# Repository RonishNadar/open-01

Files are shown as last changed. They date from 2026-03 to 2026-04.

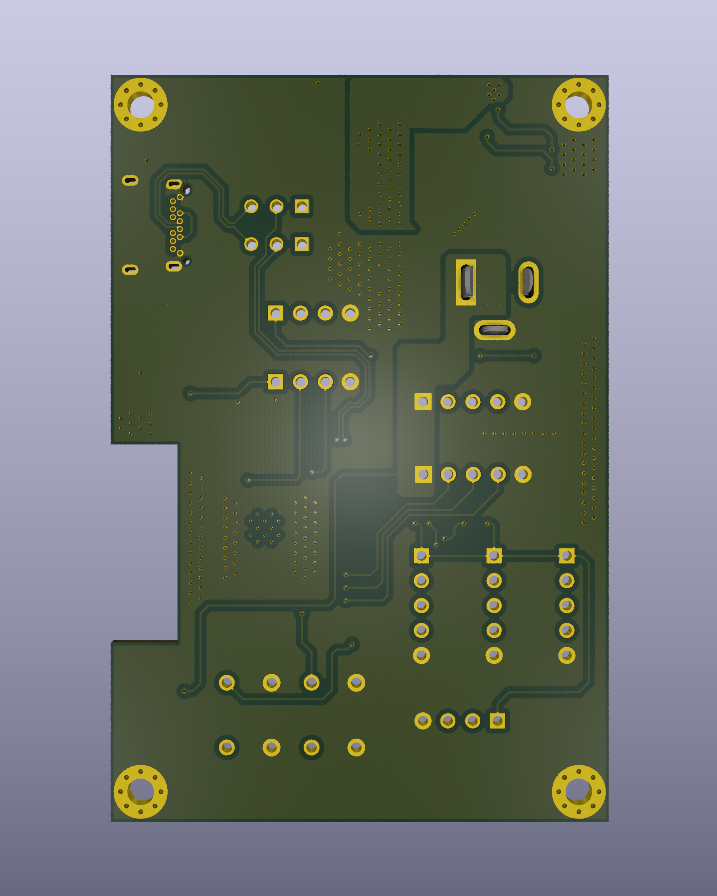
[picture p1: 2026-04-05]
pcb/images/open-01-pcb_v1.0.0_back.png

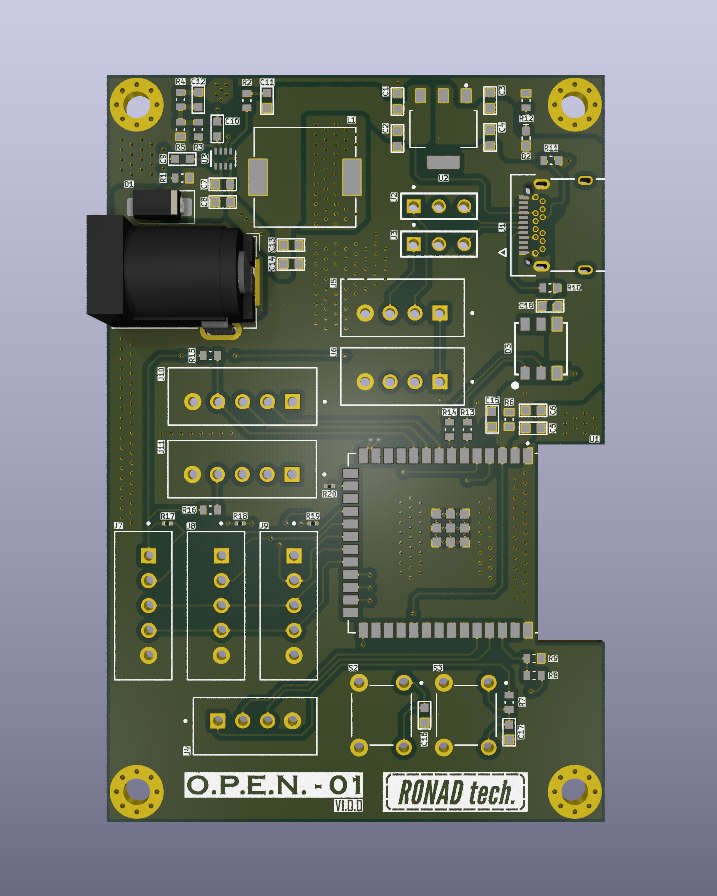
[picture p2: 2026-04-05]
pcb/images/open-01-pcb_v1.0.0_front.png

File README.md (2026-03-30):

# OPEN-01

**OPEN-01** is an open-source, low-cost differential drive robot platform focused on embedded sensing, motion control, and autonomous navigation.

This repository contains the full stack:
- ESP-IDF firmware for the ESP32-S2 robot controller
- ROS2 serial bridge and bringup for Raspberry Pi 3B
- URDF robot description with STL meshes
- RViz2 visualization stack for the dev laptop
- robot_localization EKF for sensor fusion
- Linux setup scripts for both machines

---

## What this repo is

OPEN-01 is designed as a low-cost, replicable alternative to the TurtleBot3. It is built around proven hardware and a clean layered architecture — embedded-first, with ROS2 as the autonomy layer on top.

The platform is structured around two compute nodes:

- **ESP32-S2** — handles all real-time firmware: sensors, motors, odometry, and UART telemetry
- **Raspberry Pi 3B** — runs ROS2 Humble, bridges ESP32 telemetry to ROS2 topics, and relays lidar data
- **Laptop** — runs EKF, SLAM, Nav2, and RViz2 visualization over WiFi

---

## Current capabilities

### Firmware (ESP32-S2)
- **Motor control** — FIT0441 brushless DC motors, 25kHz PWM, encoder feedback, startup kick
- **IMU** — MPU6500 (WHO_AM_I=0x70), dedicated I2C bus, accel + gyro
- **ToF ranging** — 3x VL53L0X (left, right, back), XSHUT-based address assignment
- **Odometry** — wheel encoder integration, kinematics
- **Battery monitoring** — 3S Li-Ion voltage via ADC with voltage divider
- **UART telemetry** — custom binary protocol at 460800 baud with CRC16-CCITT

### ROS2 Stack (Raspberry Pi 3B — ROS2 Humble)
- **Serial bridge node** — parses ESP32 binary protocol, publishes all sensor topics
- **Lidar node** — LDS-02 lidar via USB2LDS adapter, publishes `/scan` *(in progress)*
- **robot_state_publisher** — broadcasts full TF tree from URDF
- **Systemd autostart** — `open01.service` brings up the full stack on boot

### ROS2 Stack (Laptop — ROS2 Jazzy)
- **RViz2 visualization** — CAD model, TF frames, odometry, lidar scan
- **robot_localization EKF** — fuses `/odom` + `/imu/data` → `/odometry/filtered` at 30Hz
- **SLAM Toolbox** — *(planned)*
- **Nav2** — *(planned)*

### Published ROS2 Topics
| Topic | Type | Source |
|---|---|---|
| `/odom` | `nav_msgs/Odometry` | Serial bridge |
| `/imu/data` | `sensor_msgs/Imu` | Serial bridge |
| `/battery_state` | `sensor_msgs/BatteryState` | Serial bridge |
| `/tof/left` | `sensor_msgs/Range` | Serial bridge |
| `/tof/right` | `sensor_msgs/Range` | Serial bridge |
| `/tof/back` | `sensor_msgs/Range` | Serial bridge |
| `/scan` | `sensor_msgs/LaserScan` | Lidar node |
| `/joint_states` | `sensor_msgs/JointState` | Serial bridge |
| `/odometry/filtered` | `nav_msgs/Odometry` | EKF node |
| `/cmd_vel` | `geometry_msgs/Twist` | Nav2 / teleop |

---

## Hardware

| Component | Part |
|---|---|
| Microcontroller | ESP32-S2 |
| Companion computer | Raspberry Pi 3B |
| Motors | FIT0441 brushless DC with encoders |
| IMU | MPU6500 |
| ToF sensors | 3x VL53L0X |
| Lidar | LDS-02 (via USB2LDS adapter, CP210x) |
| Battery | 3S Li-Ion (12.6V full, 9.0V cutoff) |

### Pin Map (ESP32-S2)

| Function | GPIO |
|---|---|
| I2C Bus 0 SDA (ToF) | GPIO14 |
| I2C Bus 0 SCL (ToF) | GPIO13 |
| I2C Bus 1 SDA (IMU) | GPIO5 |
| I2C Bus 1 SCL (IMU) | GPIO4 |
| XSHUT Left (0x30) | GPIO12 |
| XSHUT Back (0x31) | GPIO11 |
| XSHUT Right (0x32) | GPIO10 |
| UART TX | GPIO19 |
| UART RX | GPIO20 |
| Motor Right PWM | GPIO15 |
| Motor Right DIR | GPIO16 |
| Motor Right FG | GPIO17 |
| Motor Left PWM | GPIO21 |
| Motor Left DIR | GPIO33 |
| Motor Left FG | GPIO34 |
| Battery ADC | GPIO2 |

---

## Repository structure

```text
open-01/
├── robot_firmware/              # ESP32-S2 firmware (ESP-IDF v5.4)
│   └── main/
│       ├── config/              # GPIO, timing, robot geometry constants
│       ├── common/              # Shared robot state
│       ├── drivers/             # MPU6500, VL53L0X, motor drivers
│       ├── hal/                 # Hardware abstraction layer
│       ├── services/            # PID, kinematics, odometry, comms
│       └── tasks/               # FreeRTOS tasks (IMU, ToF, motor, comms)
├── robot_ros2/
│   └── ros2_ws/
│       └── src/
│           ├── open01_serial_bridge/   # ESP32 <-> ROS2 bridge + lidar node
│           ├── open01_bringup/         # RPi launch files
│           ├── open01_description/     # URDF + STL meshes
│           └── open01_viz/             # Laptop RViz2 launch + EKF config
├── cad/
│   └── URDFs/                   # SolidWorks URDF export (source)
├── scripts/
│   ├── setup_rpi.sh             # One-command RPi setup
│   └── setup_laptop.sh          # One-command laptop setup
├── tools/
│   ├── launcher.py              # ESP-IDF GUI launcher
│   └── setup.sh                 # ESP-IDF toolchain setup
├── LICENSE
└── README.md
```

---

## Getting started

### RPi setup (Ubuntu 22.04 + ROS2 Humble)

```bash
git clone https://github.com/RonishNadar/open-01.git
cd open-01
sudo bash scripts/setup_rpi.sh
sudo reboot
```

### Laptop setup (Ubuntu 24.04 + ROS2 Jazzy)

```bash
git clone https://github.com/RonishNadar/open-01.git
cd open-01
sudo bash scripts/setup_laptop.sh
source ~/.bashrc
```

### Firmware setup (ESP32-S2)

```bash
chmod +x tools/setup.sh
./tools/setup.sh
python3 tools/launcher.py
```

---

## Running the robot

### On RPi (auto-starts on boot via systemd)
```bash
sudo systemctl start open01.service
sudo systemctl status open01.service
```

### Manual launch on RPi
```bash
cd ~/open-01/robot_ros2/ros2_ws
source install/setup.bash
ros2 launch open01_bringup bringup.launch.py
```

### Visualization + EKF on laptop
```bash
cd ~/open-01/robot_ros2/ros2_ws
source install/setup.bash
ros2 launch open01_viz viz.launch.py
```

### Verify topics
```bash
ros2 topic list
ros2 topic hz /odometry/filtered   # should be ~30Hz
ros2 topic hz /odom                # should be ~40Hz
ros2 topic hz /scan                # should be ~5Hz
```

### Verify TF tree
```bash
ros2 run tf2_tools view_frames
```

---

## Architecture

```
ESP32-S2 (firmware)
    |  UART 460800 baud (custom binary protocol, CRC16-CCITT)
    v
Raspberry Pi 3B (ROS2 Humble)
    |-- open01_serial_bridge  ->  /odom /imu/data /battery_state /tof/* /joint_states
    |-- lidar_node            ->  /scan
    |-- robot_state_publisher ->  /tf /tf_static
    |  WiFi (DDS, ROS_DOMAIN_ID=0)
    v
Laptop (ROS2 Jazzy)
    |-- robot_localization EKF  ->  /odometry/filtered
    |-- SLAM Toolbox            ->  /map (planned)
    |-- Nav2                    ->  autonomous navigation (planned)
    |-- RViz2                   ->  visualization
```

---

## Firmware architecture

### `config/`
Central constants: GPIO assignments, I2C/UART config, task periods, robot geometry, PID defaults.

### `common/`
Shared robot state and data structures accessed across tasks.

### `drivers/`
Low-level device drivers for MPU6500, VL53L0X, and motor control.

### `hal/`
Hardware abstraction layer separating board-specific logic from services.

### `services/`
Reusable robotics logic: PID, kinematics, odometry, motor coordination, UART comms.

### `tasks/`
FreeRTOS task entry points for periodic runtime behavior. All tasks pinned to Core 0 (ESP32-S2 is single-core).

---

## Key implementation notes

- **ESP32-S2 ADC** is 13-bit — `ADC_BITWIDTH_DEFAULT`, `BATTERY_ADC_MAX = 8191.0f`
- **FIT0441 motors** use inverted PWM (255=stop, 0=full speed), require 25kHz PWM and startup kick
- **FG pins** need 5kΩ external pull-up to 3.3V (open-collector output)
- **VL53L0X** requires full Pololu init sequence (SPAD calibration, 60+ tuning registers)
- **LDS-02 checksum** is `(~sum(bytes[0:40])) & 0xFF`, `INDEX_MAX=0xDB`
- **Serial port** on Ubuntu 22.04 RPi is `/dev/ttyS0` (not `/dev/ttyAMA0`)
- **ROS2 QoS** — RPi nodes publish `BEST_EFFORT`, set RViz2 subscriptions to match
- **EKF** — IMU orientation not fused (MPU6500 has no magnetometer), only `vyaw`, `ax`, `ay` used from IMU

---

## Project status

### Firmware
- [x] ESP-IDF firmware scaffold
- [x] Shared robot state
- [x] Motor control task + PID
- [x] IMU task (MPU6500)
- [x] ToF task (3x VL53L0X)
- [x] Odometry + kinematics
- [x] Battery monitoring
- [x] UART comms task (custom binary protocol)
- [x] Linux setup script + GUI launcher

### ROS2
- [x] Serial bridge node (ESP32 <-> ROS2)
- [~] LDS-02 lidar node *(in progress — lidar bring-up)*
- [x] URDF robot description
- [x] TF tree (all frames)
- [x] RViz2 visualization
- [x] Systemd autostart
- [x] Setup scripts (RPi + laptop)
- [x] robot_localization EKF (fusing /odom + /imu/data)
- [ ] SLAM Toolbox
- [ ] Nav2
- [ ] PID gain tuning

### Documentation
- [ ] Hardware wiring guide
- [ ] Full system bring-up docs
- [ ] Demo videos

---

## Contributing

Contributions are welcome. Good areas:

- hardware abstraction cleanup
- sensor validation and calibration
- motion control improvements
- Nav2 / SLAM configuration
- documentation and wiring diagrams
- testing utilities

When contributing:
1. keep modules focused
2. avoid hardcoding constants outside `config.h`
3. preserve the layered firmware structure
4. document any hardware assumptions clearly

---

## License

Licensed under the **Apache-2.0 License**. See [`LICENSE`](LICENSE) for details.

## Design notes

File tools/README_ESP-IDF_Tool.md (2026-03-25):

# Robot Firmware Tools

## First Time Setup (run once after cloning)

```bash
chmod +x tools/setup.sh
./tools/setup.sh
```

This will:
- Install all system dependencies (apt/dnf/pacman auto-detected)
- Clone and install ESP-IDF v5.4
- Add `idf` alias to your shell
- Add your user to the `dialout` group for USB access
- Install Python GUI dependencies

## GUI Launcher

```bash
python3 tools/launcher.py
```

| Button | What it does |
|---|---|
| Build | Compile the firmware |
| Flash | Write to ESP32-S2 |
| Monitor | Open serial monitor (Ctrl+C to stop) |
| Build+Flash+Monitor | All three in sequence |
| Clean | Full clean build |
| Stop | Kill the running command |

## CLI (alternative)

```bash
# Activate ESP-IDF in any terminal
idf

# Then use idf.py directly
cd firmware
idf.py build
idf.py -p /dev/ttyACM0 flash monitor
```

## Requirements

- Linux (Ubuntu/Debian/Fedora/Arch)
- Python 3.8+
- python3-tk (installed by setup.sh)

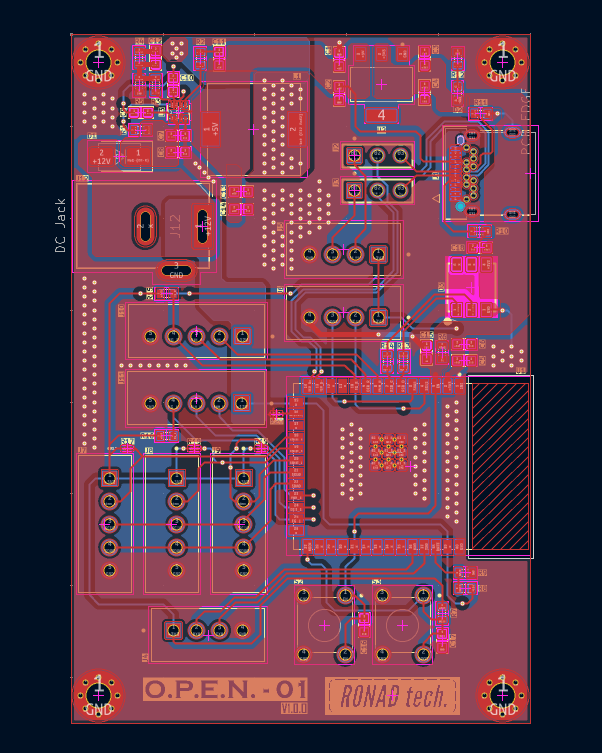
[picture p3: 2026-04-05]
pcb/images/open-01-pcb_v1.0.0_layout.png

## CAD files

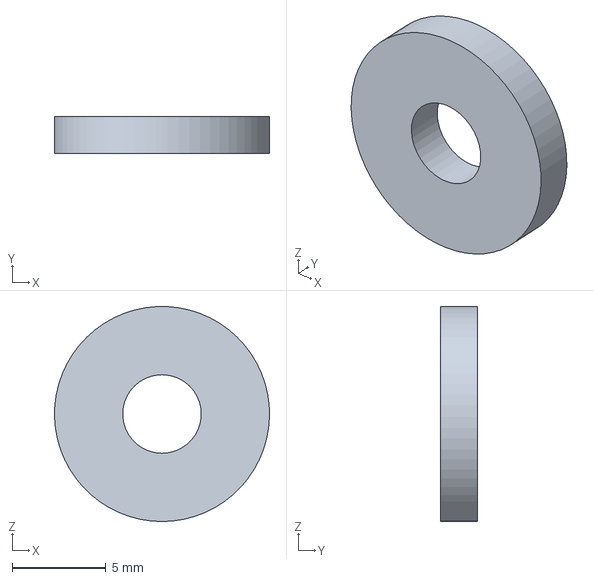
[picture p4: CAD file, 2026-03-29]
cad/3MFs/Wheel_Spacer_2mm.3MF
11.5 x 2.00 x 11.5 mm

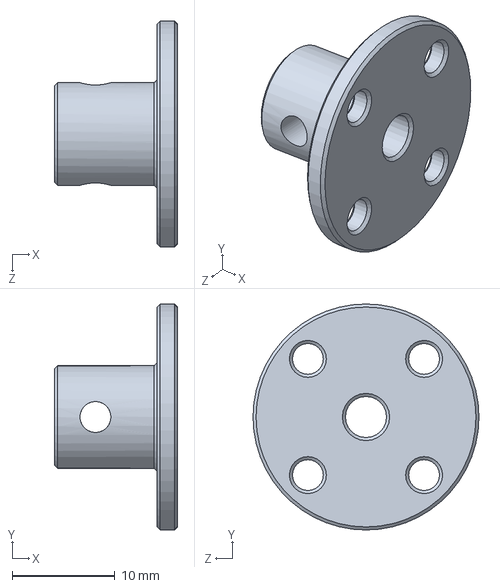
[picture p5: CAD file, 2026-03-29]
cad/Parts/Motor_Coupling_Hub_4mm.SLDPRT
12.0 x 22.0 x 22.0 mm

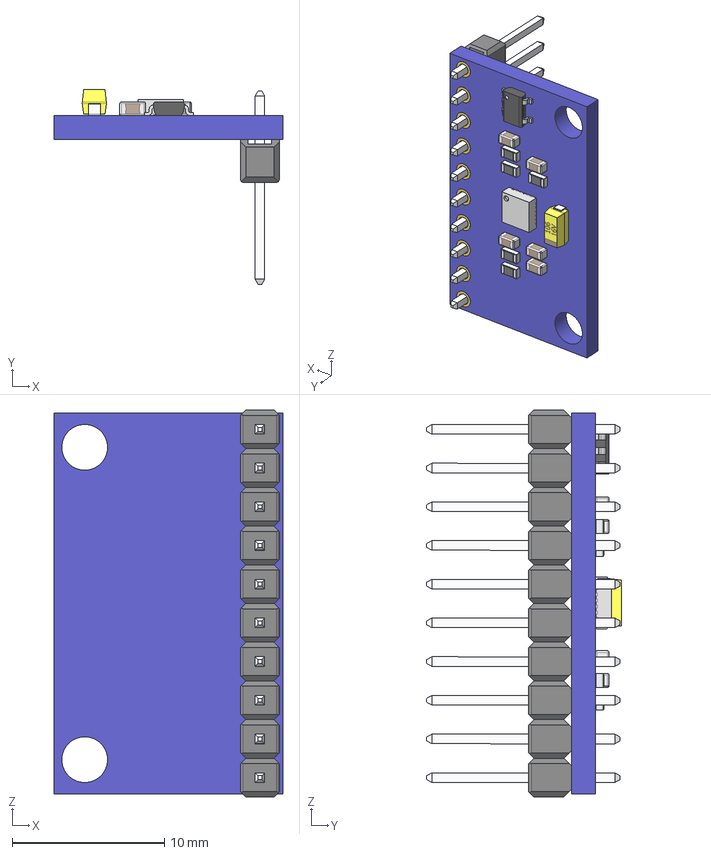
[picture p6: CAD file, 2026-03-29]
cad/STEPs/PCB_MPU_9250.stp
15.0 x 12.8 x 25.4 mm
board
hole_plating x 20
Pin Header 1x10 TH Pitch 2.54mm
MPU-9250_1
tantalum 10uF
SOT23_5
RESC-0603 x 5
CAPC-0603-T0.9-BN x 5

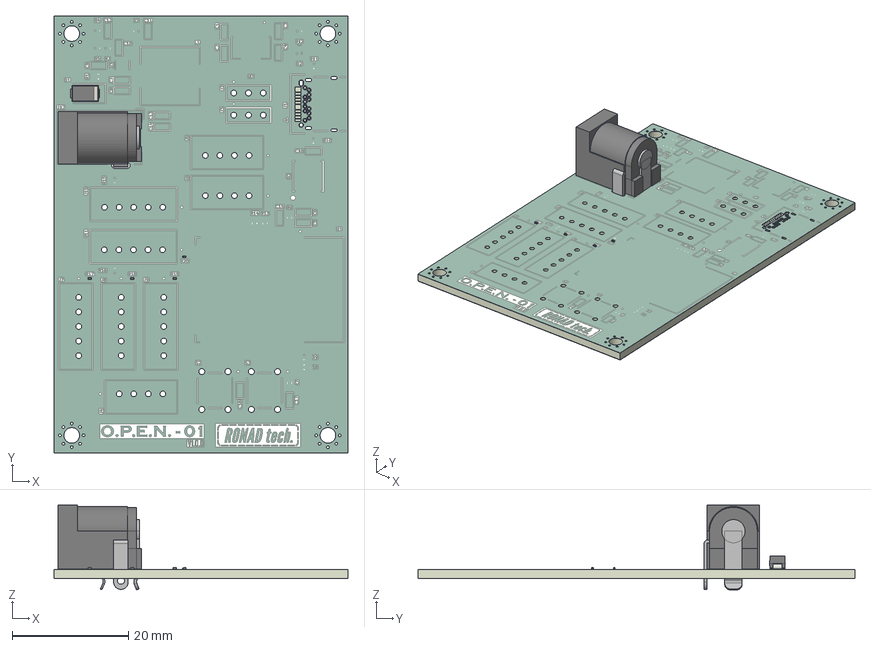
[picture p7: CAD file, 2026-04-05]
pcb/step-file/open-01-pcb_v1.0.0_step_file.step
50.5 x 75.1 x 14.6 mm
R_0201_0603Metric x 4
D_SMA
BarrelJack_GCT_DCJ200-10-A_Horizontal
open-01-pcb_silkscreen
open-01-pcb_soldermask x 2
open-01-pcb_PCB

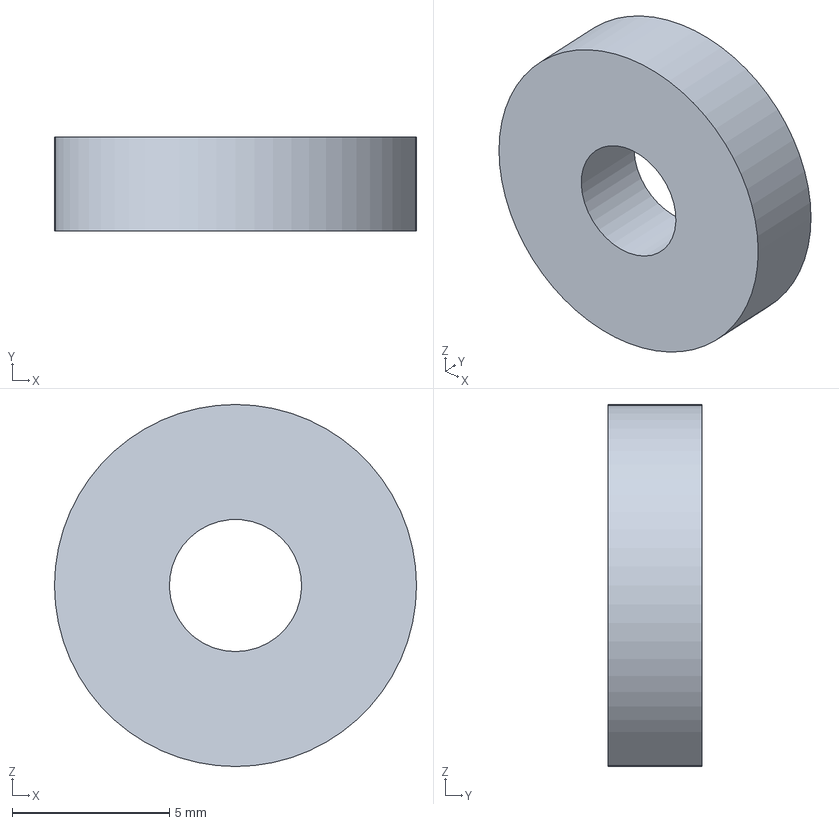
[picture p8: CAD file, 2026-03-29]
cad/3MFs/Wheel_Spacer_3mm.3MF
11.5 x 3.00 x 11.5 mm

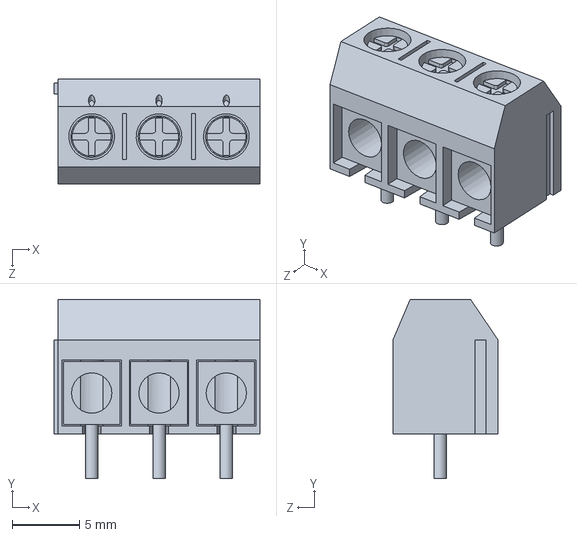
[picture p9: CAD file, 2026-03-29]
cad/Parts/PCB_Terminal_Block_3.SLDPRT
15.3 x 13.3 x 7.80 mm

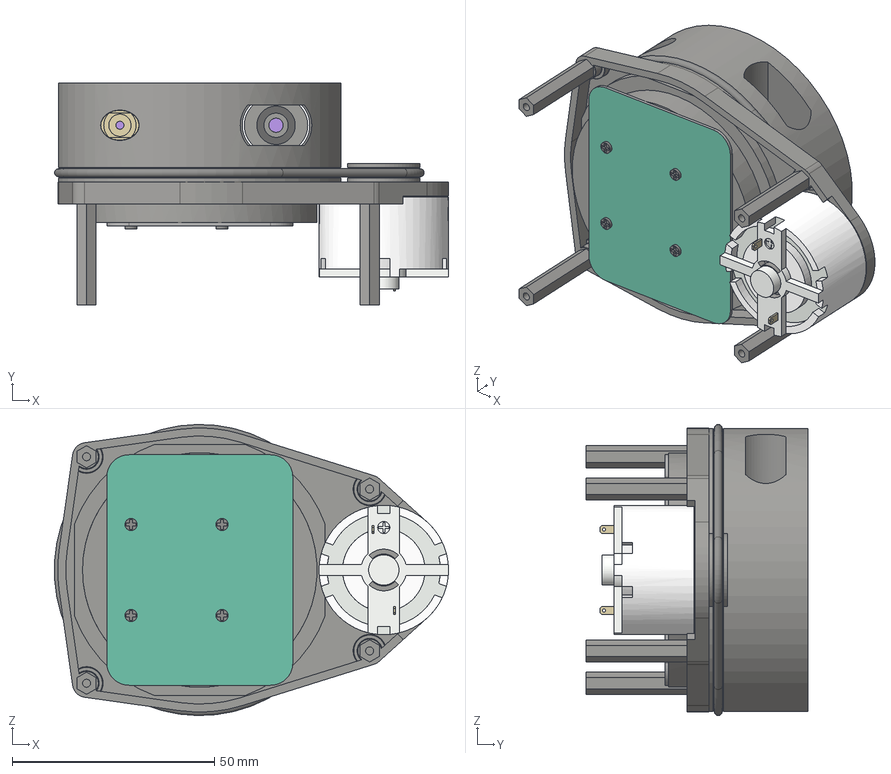
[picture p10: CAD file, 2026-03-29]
cad/STEPs/Lidar_A1M8.stp
97.4 x 55.0 x 72.0 mm

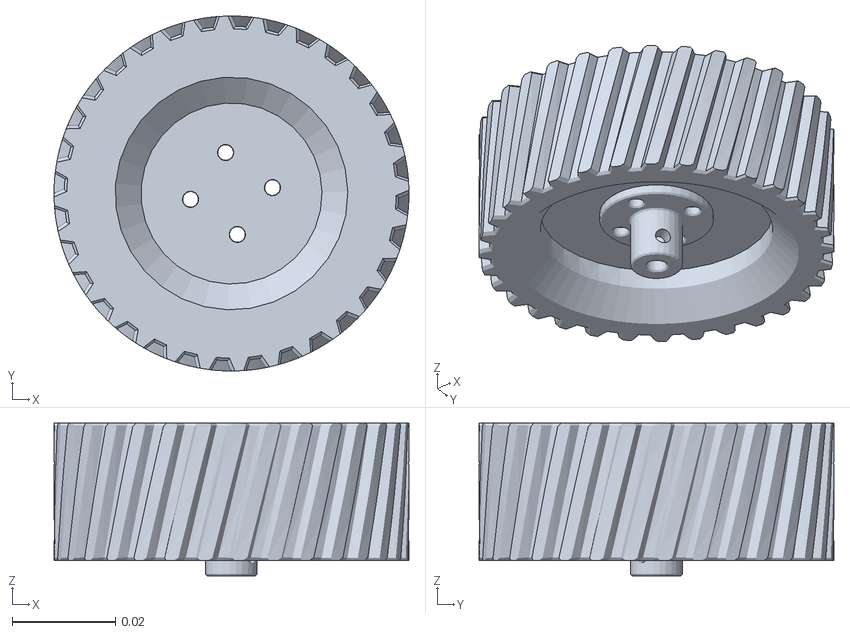
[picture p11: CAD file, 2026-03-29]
robot_ros2/ros2_ws/src/open01_description/meshes/Left_Wheel.stl
0.0686 x 0.0686 x 0.0295

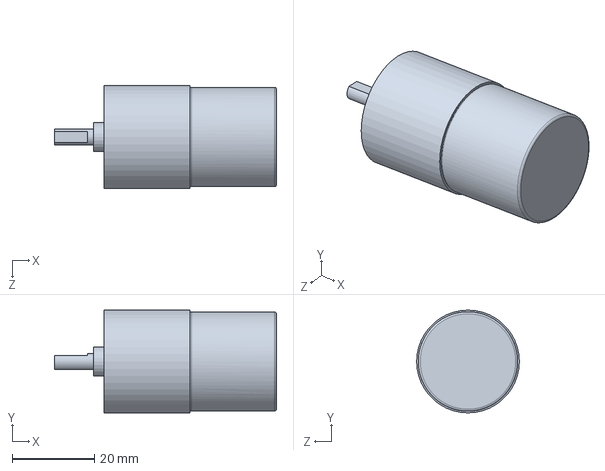
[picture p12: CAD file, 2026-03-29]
cad/Parts/DC_Motor_DF_Robot_FIT0441.SLDPRT
54.0 x 25.0 x 25.0 mm

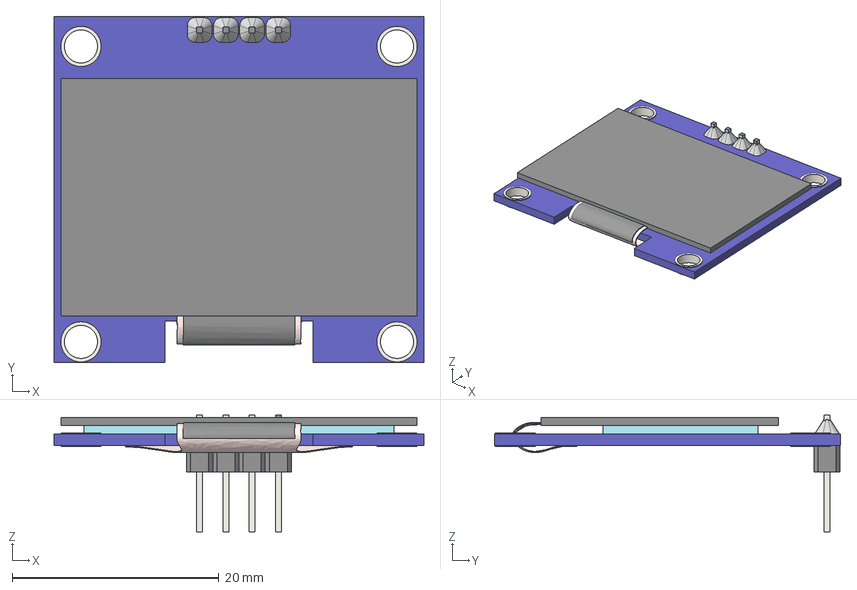
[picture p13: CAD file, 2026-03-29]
cad/STEPs/Display_OLED_1.3in.step
35.8 x 33.5 x 11.3 mm

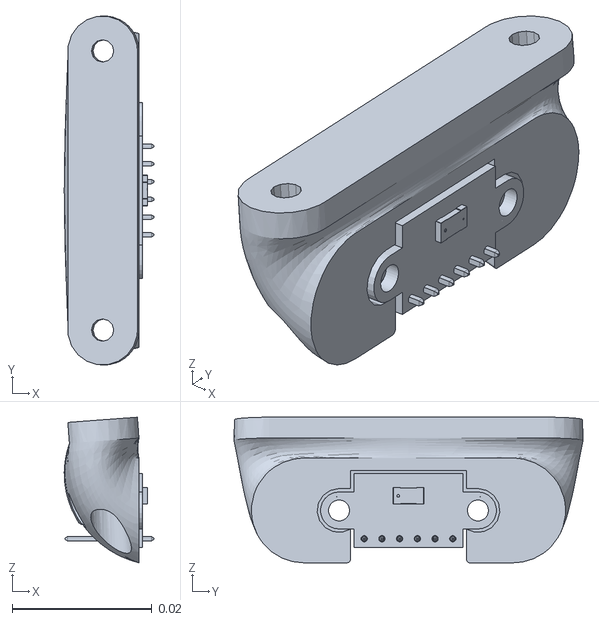
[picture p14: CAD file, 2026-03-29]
robot_ros2/ros2_ws/src/open01_description/meshes/TOF_Back.stl
0.0128 x 0.05 x 0.0209

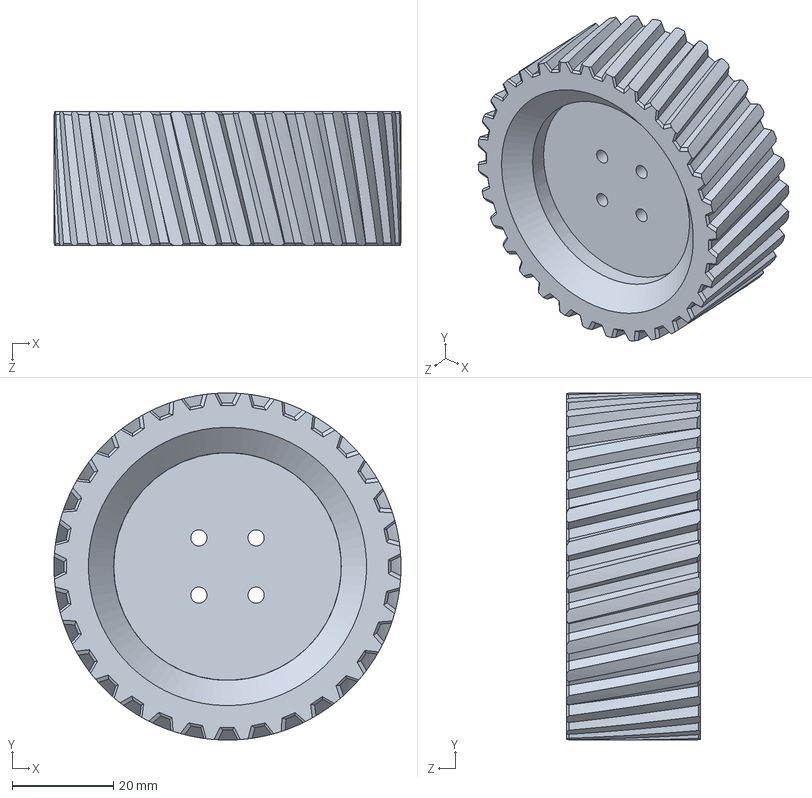
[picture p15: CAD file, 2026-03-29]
cad/Parts/Wheel_80mm_Right.SLDPRT
68.6 x 68.6 x 26.5 mm

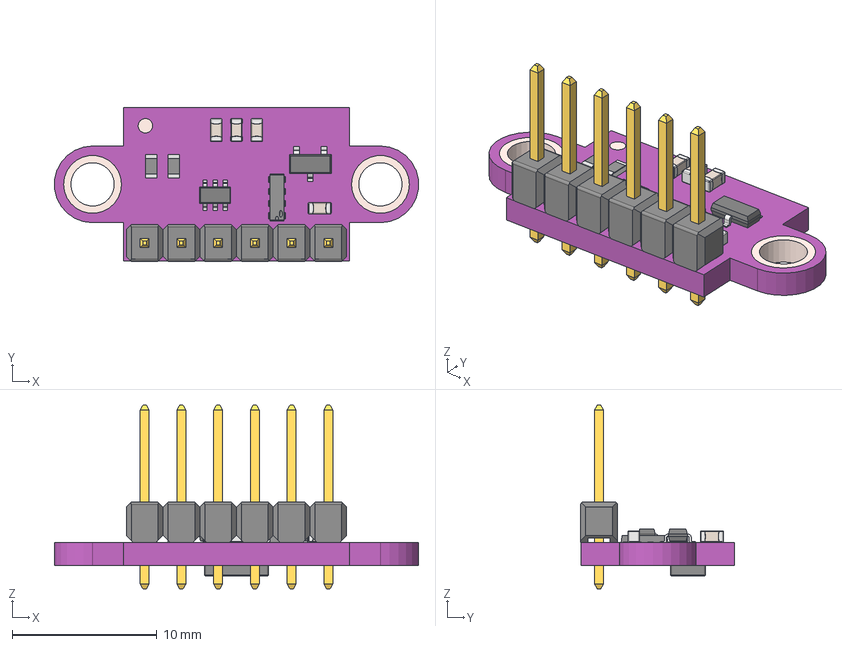
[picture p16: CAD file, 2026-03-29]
cad/STEPs/TOF_VL53L0X.step
25.2 x 10.6 x 12.7 mm
top
pcb
kork
pads
Document
Document_1
Pin1
Pin2
CeramicBody
Pin1_1
Pin2_1
CeramicBody_1
Pin1_2
Pin2_2
CeramicBody_2
Pin1_3
Pin2_3
CeramicBody_3
SOT-23-3 v1
SOT-23-6 v2
8_Pin_DIP
1x6 TH Pitch 2.54mm v1

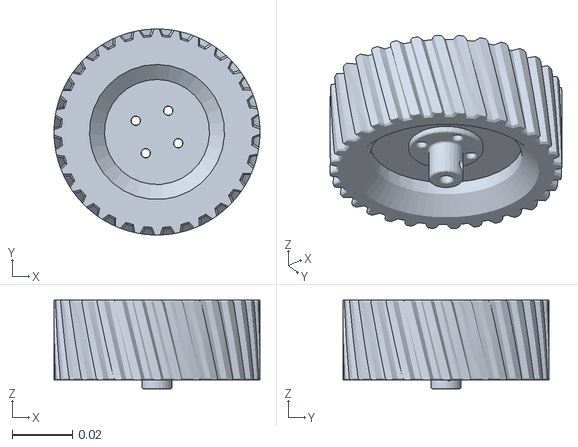
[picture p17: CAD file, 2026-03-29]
robot_ros2/ros2_ws/src/open01_description/meshes/Right_Wheel.stl
0.0686 x 0.0686 x 0.0295

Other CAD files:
robot_ros2/ros2_ws/src/open01_description/meshes/IMU.stl
cad/Parts/Display_Mount_OLED_1.3in.SLDPRT
robot_ros2/ros2_ws/src/open01_description/meshes/TOF_Left.stl
cad/Parts/Lidar_Standoff.SLDPRT
cad/3MFs/Display_Mount_OLED_1.3in.3MF
cad/3MFs/Frame_Level_0.3MF
cad/3MFs/Frame_Level_1.3MF
cad/3MFs/Frame_Level_2.3MF
cad/3MFs/Lidar_Standoff.3mf
cad/3MFs/Sensor_Holder_TOF_VL53L0X.3MF
cad/3MFs/Wheel_Castor_Adapter.3MF
cad/3MFs/Wiring_Organizer.3MF
cad/Parts/Battery_12V.SLDPRT
cad/Parts/Frame_Level_0.SLDPRT
cad/Parts/Frame_Level_1.SLDPRT
cad/Parts/Frame_Level_2.SLDPRT
cad/Parts/PCB_Board.SLDPRT
cad/Parts/PCB_Female_Pin_Header_10.SLDPRT
cad/Parts/PCB_Female_Pin_Header_22.SLDPRT
cad/Parts/Sensor_Holder_TOF_VL53L0X.SLDPRT
cad/Parts/Wheel_80mm_Left.SLDPRT
cad/Parts/Wheel_Castor.SLDPRT
cad/Parts/Wheel_Castor_Adapter.SLDPRT
cad/Parts/Wheel_Spacer.SLDPRT
cad/Parts/Wiring_Organizer.SLDPRT
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

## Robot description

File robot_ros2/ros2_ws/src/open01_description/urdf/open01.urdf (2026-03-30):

<?xml version="1.0" encoding="utf-8"?>
<robot name="open01_description">

  <link name="base_link">
    <inertial>
      <origin xyz="0.0228350285474035 -7.73458872581888E-05 0.0622801268235042" rpy="0 0 0"/>
      <mass value="0.903886172842921"/>
      <inertia ixx="0.00140829832797453" ixy="1.95394441629631E-06" ixz="1.19331191374903E-05" iyy="0.00138067792056244" iyz="-4.74315869414272E-07" izz="0.00237049117589235"/>
    </inertial>
    <visual>
      <origin xyz="0 0 0" rpy="0 0 0"/>
      <geometry>
        <mesh filename="package://open01_description/meshes/base_link.stl"/>
      </geometry>
      <material name="">
        <color rgba="0.44 0.31 0.78 1"/>
      </material>
    </visual>
    <collision>
      <origin xyz="0 0 0" rpy="0 0 0"/>
      <geometry>
        <mesh filename="package://open01_description/meshes/base_link.stl"/>
      </geometry>
    </collision>
  </link>

  <link name="Left_Wheel">
    <inertial>
      <origin xyz="8.84376602599207E-11 -5.61340834925872E-11 -5.07110154522872E-05" rpy="0 0 0"/>
      <mass value="0.0817522915412876"/>
      <inertia ixx="2.70032173523163E-05" ixy="-1.97061181019603E-09" ixz="2.55537546086817E-14" iyy="2.70020617270972E-05" iyz="-1.02853341332139E-14" izz="4.73688161589657E-05"/>
    </inertial>
    <visual>
      <origin xyz="0 0 0" rpy="0 0 0"/>
      <geometry>
        <mesh filename="package://open01_description/meshes/Left_Wheel.stl"/>
      </geometry>
      <material name="">
        <color rgba="0.2 0.2 0.2 1"/>
      </material>
    </visual>
    <collision>
      <origin xyz="0 0 0" rpy="0 0 0"/>
      <geometry>
        <mesh filename="package://open01_description/meshes/Left_Wheel.stl"/>
      </geometry>
    </collision>
  </link>

  <joint name="Left_Wheel" type="continuous">
    <origin xyz="0 0.10325 0.03432" rpy="1.5708 0 3.1416"/>
    <parent link="base_link"/>
    <child link="Left_Wheel"/>
    <axis xyz="0 0 -1"/>
  </joint>

  <link name="Right_Wheel">
    <inertial>
      <origin xyz="9.74444551762892E-11 3.84137825715225E-11 -5.07110254833049E-05" rpy="0 0 0"/>
      <mass value="0.0817523594195921"/>
      <inertia ixx="2.70043809489769E-05" ixy="1.15370227726337E-09" ixz="2.33599581416277E-14" iyy="2.70009832148061E-05" iyz="1.4594411097233E-14" izz="4.73688623615985E-05"/>
    </inertial>
    <visual>
      <origin xyz="0 0 0" rpy="0 0 0"/>
      <geometry>
        <mesh filename="package://open01_description/meshes/Right_Wheel.stl"/>
      </geometry>
      <material name="">
        <color rgba="0.1 0.1 0.1 1"/>
      </material>
    </visual>
    <collision>
      <origin xyz="0 0 0" rpy="0 0 0"/>
      <geometry>
        <mesh filename="package://open01_description/meshes/Right_Wheel.stl"/>
      </geometry>
    </collision>
  </link>

  <joint name="Right_Wheel" type="continuous">
    <origin xyz="0 -0.10325 0.03432" rpy="1.5708 0 0"/>
    <parent link="base_link"/>
    <child link="Right_Wheel"/>
    <axis xyz="0 0 -1"/>
  </joint>

  <!-- IMU: no visual/collision — empty STL -->
  <link name="IMU">
    <inertial>
      <origin xyz="-0.00102783094917421 8.81609672492741E-05 -0.00159259470994421" rpy="0 0 0"/>
      <mass value="0.000628851677164544"/>
      <inertia ixx="2.84177895500371E-08" ixy="-4.57750731552582E-14" ixz="-3.75278292675403E-14" iyy="1.06612939030682E-08" iyz="4.25878192467272E-14" izz="3.75953504496458E-08"/>
    </inertial>
  </link>

  <joint name="IMU" type="fixed">
    <origin xyz="0.01128 -0.0204 0.037774" rpy="0 0 -1.5708"/>
    <parent link="base_link"/>
    <child link="IMU"/>
    <axis xyz="0 0 0"/>
  </joint>

  <link name="TOF_Left">
    <inertial>
      <origin xyz="-0.00565170024447556 -3.8228667877914E-05 0.00315362395499548" rpy="0 0 0"/>
      <mass value="0.00645200743611607"/>
      <inertia ixx="1.14110094887023E-06" ixy="1.0454215407616E-12" ixz="1.19731699891125E-08" iyy="1.99535340907574E-07" iyz="4.76776792329873E-11" izz="1.04339638953449E-06"/>
    </inertial>
    <visual>
      <origin xyz="0 0 0" rpy="0 0 0"/>
      <geometry>
        <mesh filename="package://open01_description/meshes/TOF_Left.stl"/>
      </geometry>
      <material name="">
        <color rgba="1 0.5 0 1"/>
      </material>
    </visual>
    <collision>
      <origin xyz="0 0 0" rpy="0 0 0"/>
      <geometry>
        <mesh filename="package://open01_description/meshes/TOF_Left.stl"/>
      </geometry>
    </collision>
  </link>

  <joint name="TOF_Left" type="fixed">
    <origin xyz="0.084683 0.064317 0.080003" rpy="0 0.075049 1.0472"/>
    <parent link="base_link"/>
    <child link="TOF_Left"/>
    <axis xyz="0 0 0"/>
  </joint>

  <link name="TOF_Back">
    <inertial>
      <origin xyz="-0.00565158155130056 -3.82338496927597E-05 0.00315372066936052" rpy="0 0 0"/>
      <mass value="0.00645226052543333"/>
      <inertia ixx="1.14114359072285E-06" ixy="1.28751554081921E-12" ixz="1.19652132614046E-08" iyy="1.99535072672847E-07" iyz="4.96446137038613E-11" izz="1.04344578010352E-06"/>
    </inertial>
    <visual>
      <origin xyz="0 0 0" rpy="0 0 0"/>
      <geometry>
        <mesh filename="package://open01_description/meshes/TOF_Back.stl"/>
      </geometry>
      <material name="">
        <color rgba="1 0.5 0 1"/>
      </material>
    </visual>
    <collision>
      <origin xyz="0 0 0" rpy="0 0 0"/>
      <geometry>
        <mesh filename="package://open01_description/meshes/TOF_Back.stl"/>
      </geometry>
    </collision>
  </link>

  <joint name="TOF_Back" type="fixed">
    <origin xyz="-0.026657 -3.5E-05 0.080003" rpy="0 0.075049 -3.1416"/>
    <parent link="base_link"/>
    <child link="TOF_Back"/>
    <axis xyz="0 0 0"/>
  </joint>

  <link name="TOF_Right">
    <inertial>
      <origin xyz="-0.00565169862307091 -3.82320721003457E-05 0.00315362278201137" rpy="0 0 0"/>
      <mass value="0.00645200983079021"/>
      <inertia ixx="1.14110164868809E-06" ixy="1.00390468364293E-12" ixz="1.19734623227758E-08" iyy="1.99535573251133E-07" iyz="4.74273589081252E-11" izz="1.04339694295222E-06"/>
    </inertial>
    <visual>
      <origin xyz="0 0 0" rpy="0 0 0"/>
      <geometry>
        <mesh filename="package://open01_description/meshes/TOF_Right.stl"/>
      </geometry>
      <material name="">
        <color rgba="1 0.5 0 1"/>
      </material>
    </visual>
    <collision>
      <origin xyz="0 0 0" rpy="0 0 0"/>
      <geometry>
        <mesh filename="package://open01_description/meshes/TOF_Right.stl"/>
      </geometry>
    </collision>
  </link>

  <joint name="TOF_Right" type="fixed">
    <origin xyz="0.084744 -0.064282 0.080003" rpy="0 0.075049 -1.0472"/>
    <parent link="base_link"/>
    <child link="TOF_Right"/>
    <axis xyz="0 0 0"/>
  </joint>

</robot>

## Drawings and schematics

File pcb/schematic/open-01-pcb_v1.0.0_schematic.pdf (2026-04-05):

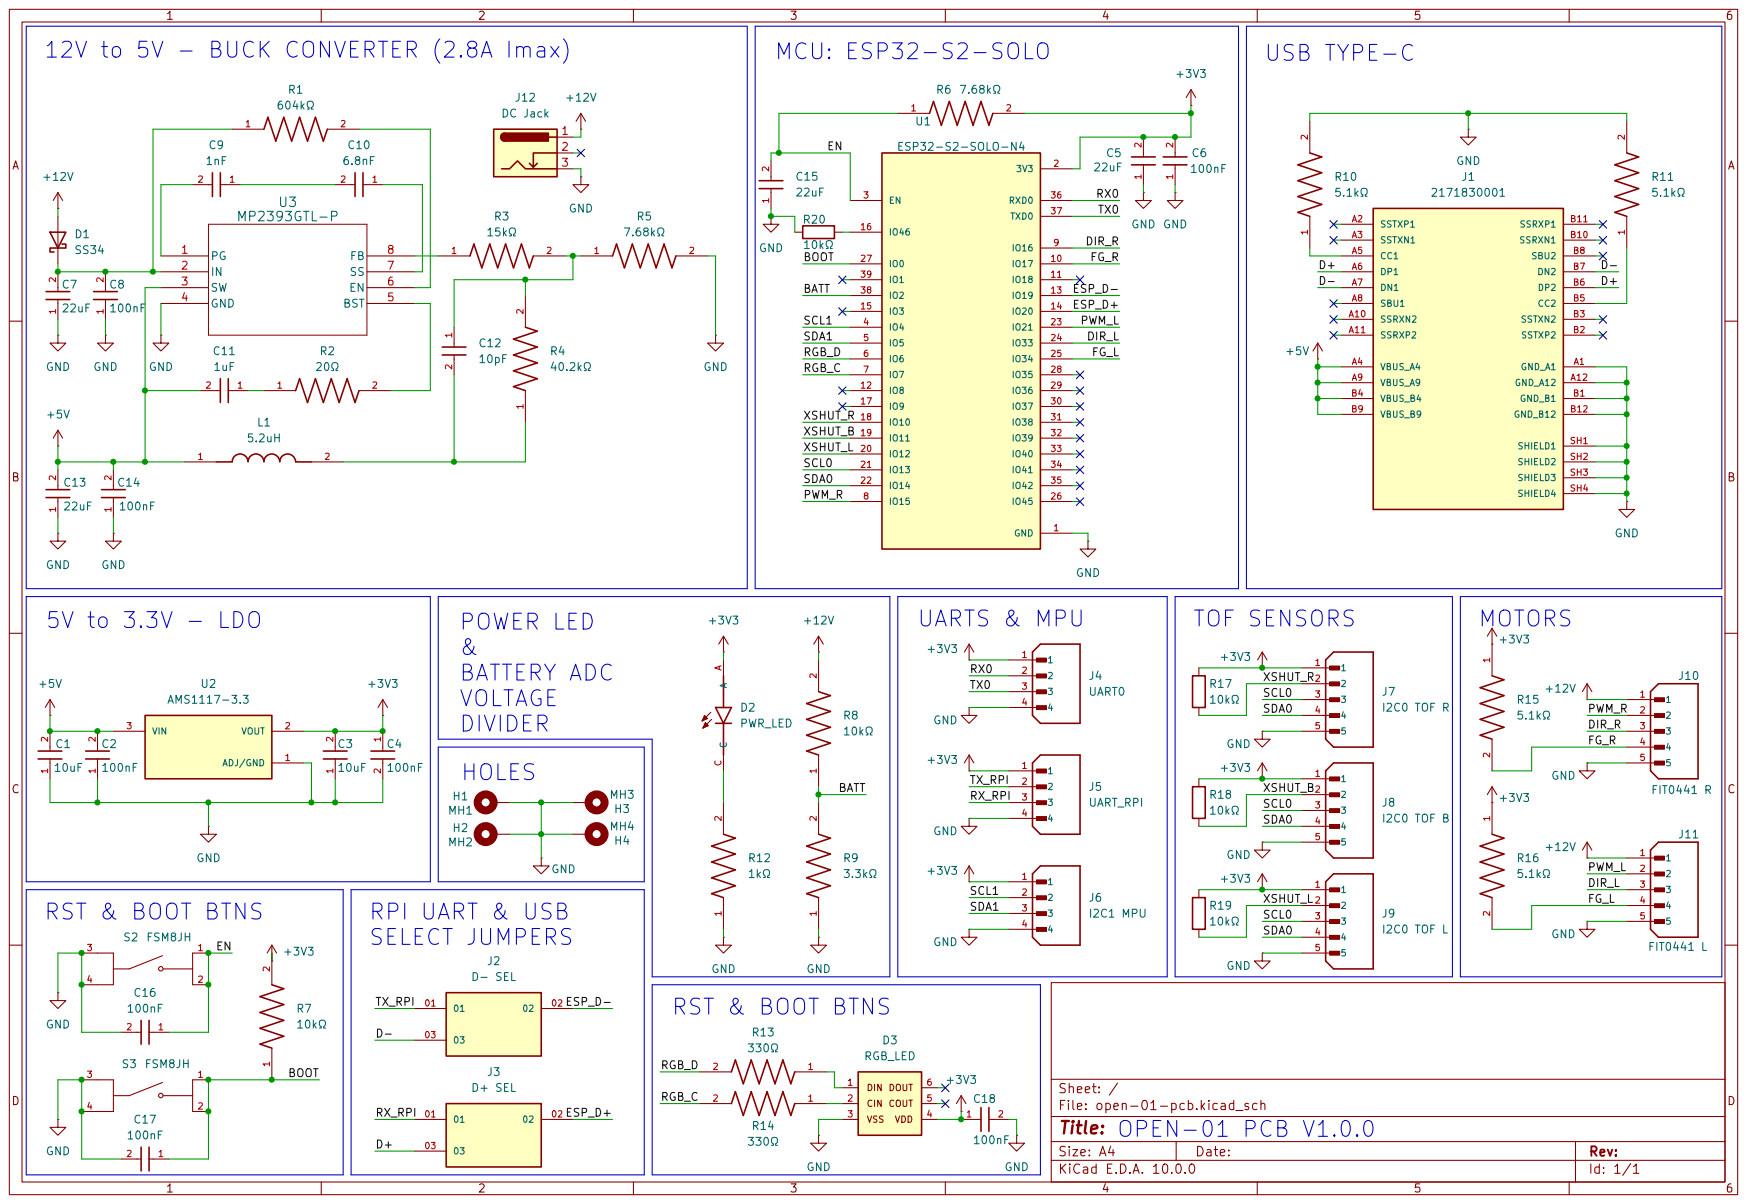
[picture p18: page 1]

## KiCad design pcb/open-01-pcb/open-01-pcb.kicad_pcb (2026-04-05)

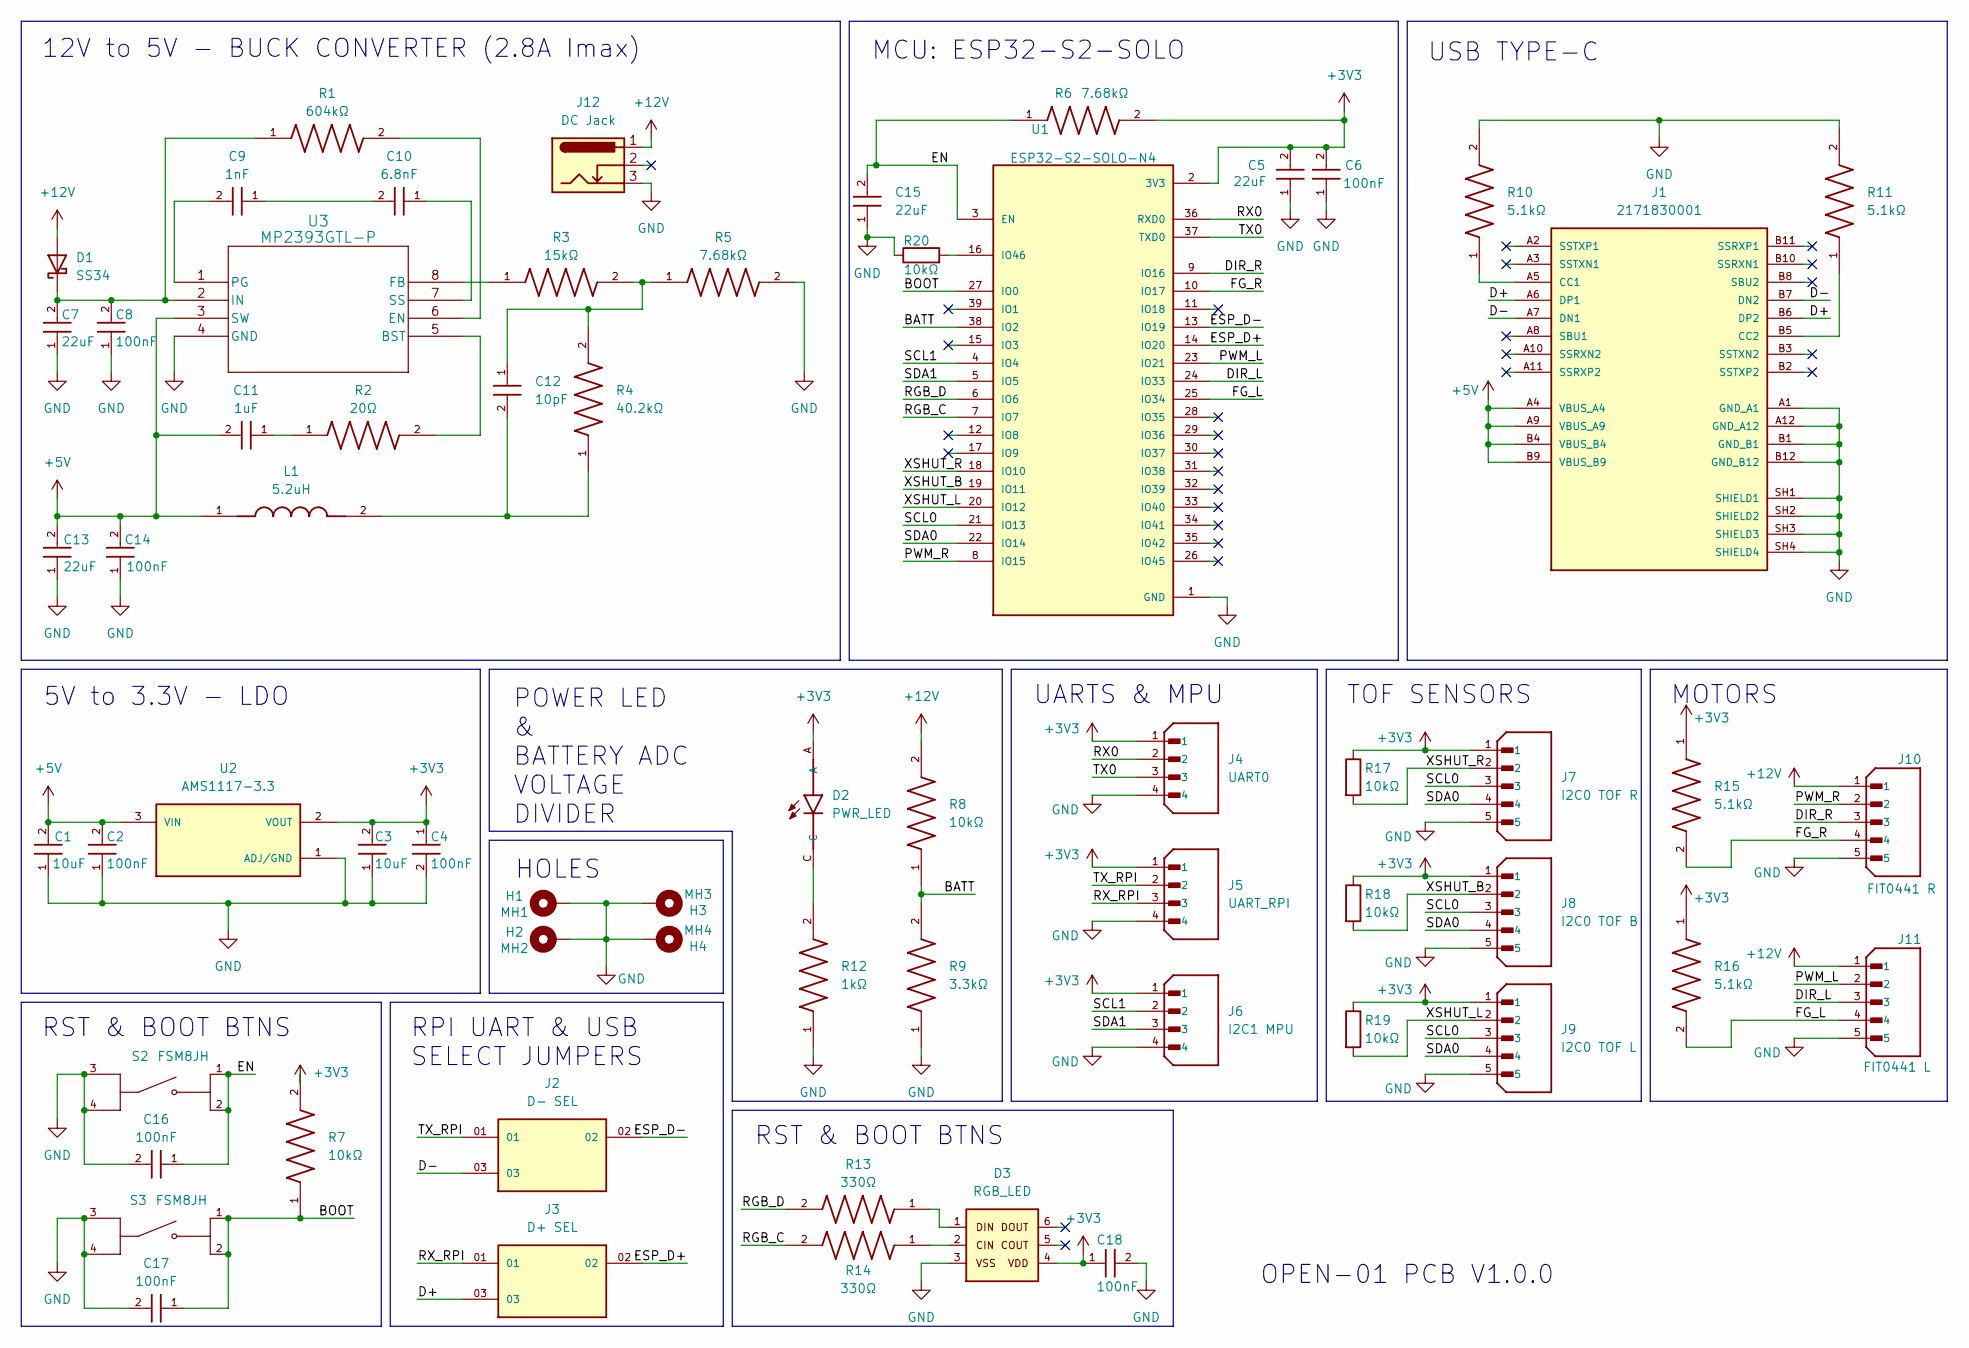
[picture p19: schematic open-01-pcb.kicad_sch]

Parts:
C1, C3: 10uF; WCAP-CSGP_0603_R
C2, C4, C6, C8, C14, C16, C17, C18: 100nF; WCAP-CSGP_0603_R
C5, C7, C13, C15: 22uF; WCAP-CSGP_0603_R
C9: 1nF; WCAP-CSGP_0603_R
C10: 6.8nF; WCAP-CSGP_0603_R
C11: 1uF; WCAP-CSGP_0603_R
C12: 10pF; WCAP-CSGP_0603_R
D1: SS34; D_SMA
D2: PWR_LED; LEDSC160X80X70L45N
D3: RGB_LED; WL-ILED_5050_PLCC6
H1: MH1; MountingHole_2.7mm_M2.5_Pad_Via
H2: MH2; MountingHole_2.7mm_M2.5_Pad_Via
H3: MH3; MountingHole_2.7mm_M2.5_Pad_Via
H4: MH4; MountingHole_2.7mm_M2.5_Pad_Via
J1: 2171830001; MOLEX_2171830001; PARTREV A1
J2: D- SEL; SAMTEC_TSW-101-17-T-T; PARTREV R
J3: D+ SEL; SAMTEC_TSW-101-17-T-T; PARTREV R
J4: UART0; JST_B4B-XH-A_LF__SN_; PARTREV 7/4/21
J5: UART_RPI; JST_B4B-XH-A_LF__SN_; PARTREV 7/4/21
J6: I2C1 MPU; JST_B4B-XH-A_LF__SN_; PARTREV 7/4/21
J7: I2C0 TOF R; JST_B5B-XH-A; PARTREV 7/4/21
J8: I2C0 TOF B; JST_B5B-XH-A; PARTREV 7/4/21
J9: I2C0 TOF L; JST_B5B-XH-A; PARTREV 7/4/21
J10: FIT0441 R; JST_B5B-XH-A; PARTREV 7/4/21
J11: FIT0441 L; JST_B5B-XH-A; PARTREV 7/4/21
J12: DC Jack; BarrelJack_GCT_DCJ200-10-A_Horizontal
L1: 5.2uH; IND_MSS1038-522NLC; PARTREV 09/27/22
R1: 604kΩ; RES_ERJU03J106V; PARTREV 3/1/2020
R2: 20Ω; RES_ERJU03J106V; PARTREV 3/1/2020
R3: 15kΩ; RES_ERJU03J106V; PARTREV 3/1/2020
R4: 40.2kΩ; RES_ERJU03J106V; PARTREV 3/1/2020
R5, R6: 7.68kΩ; RES_ERJU03J106V; PARTREV 3/1/2020
R7, R8: 10kΩ; RES_ERJU03J106V; PARTREV 3/1/2020
R9: 3.3kΩ; RES_ERJU03J106V; PARTREV 3/1/2020
R10, R11, R15, R16: 5.1kΩ; RES_ERJU03J106V; PARTREV 3/1/2020
R12: 1kΩ; RES_ERJU03J106V; PARTREV 3/1/2020
R13, R14: 330Ω; RES_ERJU03J106V; PARTREV 3/1/2020
R17, R18, R19, R20: 10kΩ; R_0201_0603Metric
S2, S3: FSM8JH; SW_FSM8JH; PARTREV 8-1773450-9
U1: ESP32-S2-SOLO-N4; XCVR_ESP32-S2-SOLO-N4; PARTREV 1.6
U2: AMS1117-3.3; SOT229P700X180-4N; PARTREV NA
U3: MP2393GTL-P; SOT583_MP2393

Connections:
+3V3: C3.2, C4.1, C5.2, C6.2, C18.1, D2.A, D3.4, J4.1, J5.1, J6.1, J7.1, J8.1, J9.1, R6.2, R7.2, R15.1, R16.1, R17.1, R18.1, R19.1, U1.2 (3V3), U2.2 (VOUT)
+5V: C1.2, C2.2, C11.2, C13.2, C14.2, J1.A4 (VBUS_A4), J1.A9 (VBUS_A9), J1.B4 (VBUS_B4), J1.B9 (VBUS_B9), L1.1, U2.3 (VIN), U3.3 (SW)
+12V: D1.2 (A), J10.1, J11.1, J12.1, R8.2
/BATT: R8.1, R9.2, U1.38 (IO2)
/BOOT: C17.1, R7.1, S3.1, S3.2, U1.27 (IO0)
/D+: J1.A6 (DP1), J1.B6 (DP2), J3.03
/D-: J1.A7 (DN1), J1.B7 (DN2), J2.03
/DIR_L: J11.3, U1.24 (IO33)
/DIR_R: J10.3, U1.9 (IO16)
/EN: C15.2, C16.1, R6.1, S2.1, S2.2, U1.3 (EN)
/ESP_D+: J3.02, U1.14 (IO20)
/ESP_D-: J2.02, U1.13 (IO19)
/FG_L: J11.4, R16.2, U1.25 (IO34)
/FG_R: J10.4, R15.2, U1.10 (IO17)
/PWM_L: J11.2, U1.23 (IO21)
/PWM_R: J10.2, U1.8 (IO15)
/RGB_C: R14.2, U1.7 (IO7)
/RGB_D: R13.2, U1.6 (IO6)
/RX0: J4.2, U1.36 (RXD0)
/RX_RPI: J3.01, J5.3
/SCL0: J7.3, J8.3, J9.3, U1.21 (IO13)
/SCL1: J6.2, U1.4 (IO4)
/SDA0: J7.4, J8.4, J9.4, U1.22 (IO14)
/SDA1: J6.3, U1.5 (IO5)
/TX0: J4.3, U1.37 (TXD0)
/TX_RPI: J2.01, J5.2
/XSHUT_B: J8.2, R18.2, U1.19 (IO11)
/XSHUT_L: J9.2, R19.2, U1.20 (IO12)
/XSHUT_R: J7.2, R17.2, U1.18 (IO10)
GND: C1.1, C2.1, C3.1, C4.2, C5.1, C6.1, C7.1, C8.1, C13.1, C14.1, C15.1, C16.2, C17.2, C18.2, D3.3, H1.1 (1_1), H2.1 (1_1), H3.1 (1_1), H4.1 (1_1), J1.A1 (GND_A1), J1.A12 (GND_A12), J1.B1 (GND_B1), J1.B12 (GND_B12), J1.SH1 (SHIELD1), J1.SH2 (SHIELD2), J1.SH3 (SHIELD3), J1.SH4 (SHIELD4), J4.4, J5.4, J6.4, J7.5, J8.5, J9.5, J10.5, J11.5, J12.3, R5.2, R9.1, R10.2, R11.2, R12.1, R20.1, S2.3, S2.4, S3.3, S3.4, U1.1 (GND), U1.40 (GND), U1.41_1 (GND), U1.41_2 (GND), U1.41_3 (GND), U1.41_4 (GND), U1.41_5 (GND), U1.41_6 (GND), U1.41_7 (GND), U1.41_8 (GND), U1.41_9 (GND), U2.1 (ADJ/GND), U3.4 (GND)
unnamed: C9.1, C10.2
unnamed: C11.1, R2.1
unnamed: C12.1, R3.2, R4.2, R5.1
unnamed: C12.2, L1.2, R4.1
unnamed: C7.2, C8.2, D1.1 (K), R1.1, U3.2 (IN)
unnamed: D2.C, R12.2
unnamed: D3.1, R13.1
unnamed: D3.2, R14.1
unnamed: J1.A5 (CC1), R10.1
unnamed: J1.B5 (CC2), R11.1
unnamed: R20.2, U1.16 (IO46)
unnamed: R2.2, U3.5 (BST)
unnamed: R1.2, U3.6 (EN)
unnamed: R3.1, U3.8 (FB)
unnamed: C9.2, U3.1 (PG)
unnamed: C10.1, U3.7 (SS)

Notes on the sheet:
RPI UART & USB SELECT JUMPERS
OPEN-01 PCB V1.0.0
RST & BOOT BTNS
POWER LED & BATTERY ADC VOLTAGE DIVIDER
12V to 5V - BUCK CONVERTER (2.8A Imax)
MOTORS
HOLES
MCU: ESP32-S2-SOLO
UARTS & MPU
TOF SENSORS
5V to 3.3V - LDO
USB TYPE-C

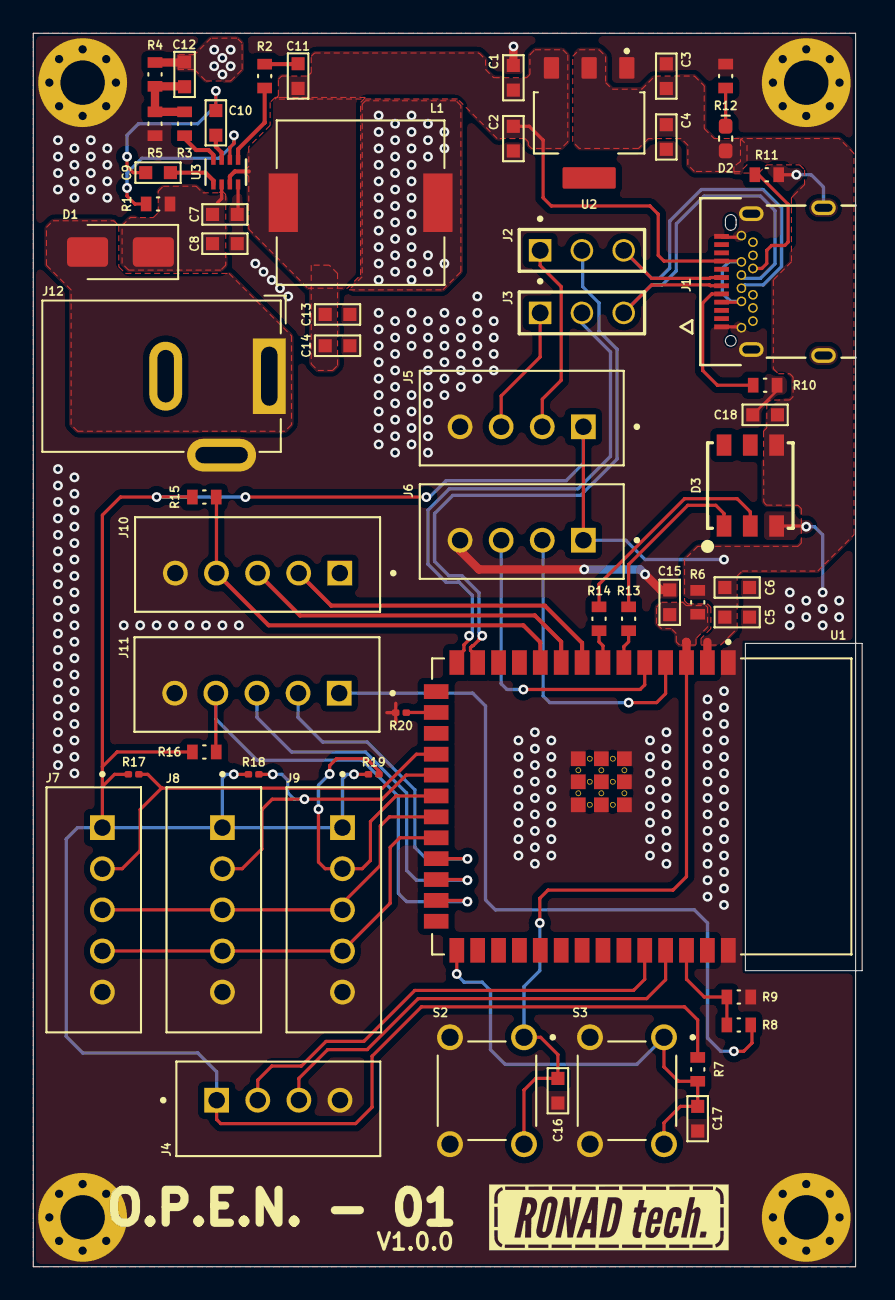
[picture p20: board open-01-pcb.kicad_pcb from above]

Board: 2 copper layers, 50.0 x 75.0 mm, 63 parts (0 on the bottom side), 46 nets.

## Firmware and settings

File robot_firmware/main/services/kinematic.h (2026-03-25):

#pragma once

#ifdef __cplusplus
extern "C" {
#endif

// =============================================================
//  kinematic.h — Differential drive kinematics
//  Pure math — no hardware dependencies
// =============================================================

typedef struct {
    float linear_ms;    // m/s forward
    float angular_rs;   // rad/s rotation
} cmd_vel_t;

typedef struct {
    float left_ms;      // m/s
    float right_ms;     // m/s
} wheel_vel_t;

// cmd_vel → wheel velocities
// v_left  = linear - (angular × separation / 2)
// v_right = linear + (angular × separation / 2)
void kinematic_cmd_to_wheels(const cmd_vel_t* cmd,
                              wheel_vel_t* out,
                              float wheel_separation_m);

// wheel velocities → cmd_vel (inverse)
void kinematic_wheels_to_cmd(const wheel_vel_t* wheels,
                              cmd_vel_t* out,
                              float wheel_separation_m);

#ifdef __cplusplus
}
#endif

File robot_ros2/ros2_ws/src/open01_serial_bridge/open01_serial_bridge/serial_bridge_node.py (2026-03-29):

#!/usr/bin/env python3
"""
OPEN-01 Serial Bridge Node
Bridges ESP32 binary UART protocol <-> ROS2 topics.

Packet format:
  [0xAA][0x55][VERSION][MSG_TYPE][PAYLOAD_LEN][...PAYLOAD...][CRC_HI][CRC_LO][0xFF]
  CRC16-CCITT (init=0xFFFF, poly=0x1021) over [VERSION, MSG_TYPE, PAYLOAD_LEN, ...PAYLOAD]

RX thread feeds a ring buffer; state machine parses packets.
ROS2 spin thread handles all publishing + cmd_vel TX.
"""

import struct
import threading
import time
from collections import deque

import rclpy
from rclpy.node import Node
from rclpy.qos import QoSProfile, ReliabilityPolicy, HistoryPolicy

import serial

from std_msgs.msg import Float32
from sensor_msgs.msg import Imu, BatteryState, Range, JointState
from nav_msgs.msg import Odometry
from geometry_msgs.msg import Twist, TransformStamped
from tf2_ros import TransformBroadcaster

import math

# ─── Protocol constants ────────────────────────────────────────────────────────
FRAME_START_1   = 0xAA
FRAME_START_2   = 0x55
FRAME_END       = 0xFF
PROTOCOL_VER    = 0x01

MSG_CMD_VELOCITY = 0x10
MSG_CMD_ESTOP    = 0x11
MSG_CMD_PING     = 0x12
MSG_TELEMETRY    = 0x20
MSG_PONG         = 0x21

SUB_IMU       = 0x01   # 24B: 6x float (ax, ay, az, gx, gy, gz)
SUB_TOF       = 0x02   # 6B:  3x uint16 (left, back, right) mm
SUB_ODOM      = 0x03   # 24B: 6x float (x, y, theta, linear, angular, unused)
SUB_BATTERY   = 0x04   # 4B:  float voltage
SUB_TIMESTAMP = 0x05   # 4B:  uint32 ms

# ─── CRC16-CCITT ───────────────────────────────────────────────────────────────

def crc16_ccitt(data: bytes, init: int = 0x0000) -> int:
    """CRC16-CCITT (poly=0x1021). Matches ESP32 firmware implementation."""
    crc = init
    for byte in data:
        crc ^= (byte << 8)
        for _ in range(8):
            if crc & 0x8000:
                crc = ((crc << 1) ^ 0x1021) & 0xFFFF
            else:
                crc = (crc << 1) & 0xFFFF
    return crc

# ─── Packet builder ────────────────────────────────────────────────────────────

def build_packet(msg_type: int, payload: bytes) -> bytes:
    """Construct a framed packet with CRC."""
    version = PROTOCOL_VER
    payload_len = len(payload)
    crc_data = bytes([version, msg_type, payload_len]) + payload
    crc = crc16_ccitt(crc_data)
    return bytes([
        FRAME_START_1, FRAME_START_2,
        version, msg_type, payload_len,
        *payload,
        (crc >> 8) & 0xFF, crc & 0xFF,
        FRAME_END
    ])

# ─── Parser state machine ──────────────────────────────────────────────────────

class PacketParser:
    """
    State machine that pulls bytes one at a time and emits complete packets.
    States: WAIT_START1 → WAIT_START2 → VERSION → MSG_TYPE → PAYLOAD_LEN
            → PAYLOAD → CRC_HI → CRC_LO → END
    """

    WAIT_START1  = 0
    WAIT_START2  = 1
    VERSION      = 2
    MSG_TYPE     = 3
    PAYLOAD_LEN  = 4
    PAYLOAD      = 5
    CRC_HI       = 6
    CRC_LO       = 7
    END          = 8

    def __init__(self):
        self._state       = self.WAIT_START1
        self._version     = 0
        self._msg_type    = 0
        self._payload_len = 0
        self._payload     = bytearray()
        self._crc_hi      = 0
        self._packets     = deque()
        self.bytes_rx     = 0
        self.packets_ok   = 0
        self.crc_errors   = 0
        self.frame_errors = 0

    def feed(self, data: bytes):
        for byte in data:
            self.bytes_rx += 1
            self._process_byte(byte)

    def _reset(self):
        self._state   = self.WAIT_START1
        self._payload = bytearray()

    def _process_byte(self, b: int):
        s = self._state

        if s == self.WAIT_START1:
            if b == FRAME_START_1:
                self._state = self.WAIT_START2

        elif s == self.WAIT_START2:
            if b == FRAME_START_2:
                self._state = self.VERSION
            else:
                self.frame_errors += 1
                self._reset()

        elif s == self.VERSION:
            self._version = b
            self._state = self.MSG_TYPE

        elif s == self.MSG_TYPE:
            self._msg_type = b
            self._state = self.PAYLOAD_LEN

        elif s == self.PAYLOAD_LEN:
            self._payload_len = b
            self._payload = bytearray()
            if b == 0:
                self._state = self.CRC_HI
            else:
                self._state = self.PAYLOAD

        elif s == self.PAYLOAD:
            self._payload.append(b)
            if len(self._payload) == self._payload_len:
                self._state = self.CRC_HI

        elif s == self.CRC_HI:
            self._crc_hi = b
            self._state = self.CRC_LO

        elif s == self.CRC_LO:
            received_crc = (self._crc_hi << 8) | b
            crc_input = bytes([self._version, self._msg_type, self._payload_len]) \
                        + bytes(self._payload)
            expected_crc = crc16_ccitt(crc_input)
            if received_crc == expected_crc:
                self._state = self.END
            else:
                self.crc_errors += 1
                self._reset()

        elif s == self.END:
            if b == FRAME_END:
                self._packets.append((self._msg_type, bytes(self._payload)))
                self.packets_ok += 1
            else:
                self.frame_errors += 1
            self._reset()

    def pop_packet(self):
        return self._packets.popleft() if self._packets else None

    def has_packet(self) -> bool:
        return len(self._packets) > 0

# ─── Main node ─────────────────────────────────────────────────────────────────

class SerialBridgeNode(Node):

    # Wheel geometry from URDF
    WHEEL_BASE   = 0.2065    # y offset = 0.10325 * 2
    WHEEL_RADIUS = 0.03432   # z offset from base_link to wheel center

    def __init__(self):
        super().__init__('serial_bridge')

        # ── Parameters ──
        self.declare_parameter('port',          '/dev/ttyS0')
        self.declare_parameter('baud',          460800)
        self.declare_parameter('base_frame_id', 'base_link')
        self.declare_parameter('odom_frame_id', 'odom')
        self.declare_parameter('imu_frame_id',  'imu_link')
        self.declare_parameter('publish_tf',    True)

        port             = self.get_parameter('port').value
        baud             = self.get_parameter('baud').value
        self._base_frame = self.get_parameter('base_frame_id').value
        self._odom_frame = self.get_parameter('odom_frame_id').value
        self._imu_frame  = self.get_parameter('imu_frame_id').value
        self._publish_tf = self.get_parameter('publish_tf').value

        # ── Serial port ──
        try:
            self._serial = serial.Serial(
                port=port,
                baudrate=baud,
                bytesize=serial.EIGHTBITS,
                parity=serial.PARITY_NONE,
                stopbits=serial.STOPBITS_ONE,
                timeout=0.02,
            )
            self.get_logger().info(f'Opened serial port {port} @ {baud} baud')
        except serial.SerialException as e:
            self.get_logger().fatal(f'Cannot open serial port {port}: {e}')
            raise

        self._parser      = PacketParser()
        self._serial_lock = threading.Lock()

        # ── QoS ──
        sensor_qos = QoSProfile(
            reliability=ReliabilityPolicy.BEST_EFFORT,
            history=HistoryPolicy.KEEP_LAST,
            depth=10
        )

        # ── Publishers ──
        self._pub_odom         = self.create_publisher(Odometry,     '/odom',          sensor_qos)
        self._pub_imu          = self.create_publisher(Imu,          '/imu/data',      sensor_qos)
        self._pub_battery      = self.create_publisher(BatteryState, '/battery_state', sensor_qos)
        self._pub_tof_l        = self.create_publisher(Range,        '/tof/left',      sensor_qos)
        self._pub_tof_b        = self.create_publisher(Range,        '/tof/back',      sensor_qos)
        self._pub_tof_r        = self.create_publisher(Range,        '/tof/right',     sensor_qos)
        self._pub_joint_states = self.create_publisher(JointState,   '/joint_states',  sensor_qos)

        # ── TF broadcaster ──
        if self._publish_tf:
            self._tf_broadcaster = TransformBroadcaster(self)

        # ── Subscriber ──
        self._sub_cmdvel = self.create_subscription(
            Twist, '/cmd_vel', self._cmd_vel_cb, 10)

        # ── Timers ──
        self._rx_timer   = self.create_timer(0.01, self._rx_timer_cb)
        self._diag_timer = self.create_timer(5.0,  self._diag_cb)

        # ── RX thread ──
        self._rx_buf      = deque()
        self._rx_buf_lock = threading.Lock()
        self._running     = True
        self._rx_thread   = threading.Thread(target=self._rx_thread_fn, daemon=True)
        self._rx_thread.start()

        # ── Wheel position accumulators ──
        self._wheel_left_pos  = 0.0
        self._wheel_right_pos = 0.0
        self._last_odom_time  = None

        self.get_logger().info('serial_bridge node started')

    # ── RX thread ────────────────────────────────────────────────────────────

    def _rx_thread_fn(self):
        while self._running:
            try:
                data = self._serial.read(256)
                if data:
                    with self._rx_buf_lock:
                        self._rx_buf.append(data)
            except serial.SerialException as e:
                self.get_logger().error(f'Serial read error: {e}')
                time.sleep(0.1)

    # ── RX timer ─────────────────────────────────────────────────────────────

    def _rx_timer_cb(self):
        chunks = []
        with self._rx_buf_lock:
            while self._rx_buf:
                chunks.append(self._rx_buf.popleft())

        for chunk in chunks:
            self._parser.feed(chunk)

        while self._parser.has_packet():
            msg_type, payload = self._parser.pop_packet()
            self._dispatch_packet(msg_type, payload)

    def _dispatch_packet(self, msg_type: int, payload: bytes):
        if msg_type == MSG_TELEMETRY:
            self._parse_telemetry(payload)
        elif msg_type == MSG_PONG:
            self.get_logger().debug('PONG received')
        else:
            self.get_logger().warn(f'Unknown msg_type: 0x{msg_type:02X}')

    # ── Telemetry parser ─────────────────────────────────────────────────────

    def _parse_telemetry(self, payload: bytes):
        now = self.get_clock().now().to_msg()
        idx = 0
        imu_data = odom_data = tof_data = battery_data = ts_data = None

        while idx + 2 <= len(payload):
            sub_id  = payload[idx]
            sub_len = payload[idx + 1]
            idx += 2

            if idx + sub_len > len(payload):
                self.get_logger().warn('Telemetry sub-block truncated')
                break

            sub_payload = payload[idx:idx + sub_len]
            idx += sub_len

            if sub_id == SUB_IMU and sub_len == 24:
                imu_data = struct.unpack_from('<6f', sub_payload)
            elif sub_id == SUB_TOF and sub_len == 6:
                tof_data = struct.unpack_from('<3H', sub_payload)
            elif sub_id == SUB_ODOM and sub_len == 24:
                odom_data = struct.unpack_from('<6f', sub_payload)
            elif sub_id == SUB_BATTERY and sub_len == 4:
                battery_data = struct.unpack_from('<f', sub_payload)[0]
            elif sub_id == SUB_TIMESTAMP and sub_len == 4:
                ts_data = struct.unpack_from('<I', sub_payload)[0]
            else:
                self.get_logger().debug(
                    f'Unknown sub_id=0x{sub_id:02X} len={sub_len}')

        if imu_data     is not None: self._publish_imu(imu_data, now)
        if odom_data    is not None: self._publish_odom(odom_data, now)
        if tof_data     is not None: self._publish_tof(tof_data, now)
        if battery_data is not None: self._publish_battery(battery_data, now)

    # ── Publishers ───────────────────────────────────────────────────────────

    def _publish_imu(self, data, stamp):
        ax, ay, az, gx, gy, gz = data
        msg = Imu()
        msg.header.stamp    = stamp
        msg.header.frame_id = self._imu_frame

        msg.linear_acceleration.x = ax
        msg.linear_acceleration.y = ay
        msg.linear_acceleration.z = az
        msg.angular_velocity.x    = gx
        msg.angular_velocity.y    = gy
        msg.angular_velocity.z    = gz

        msg.orientation_covariance[0]          = -1.0
        msg.linear_acceleration_covariance[0]  = 0.01
        msg.linear_acceleration_covariance[4]  = 0.01
        msg.linear_acceleration_covariance[8]  = 0.01
        msg.angular_velocity_covariance[0]     = 0.001
        msg.angular_velocity_covariance[4]     = 0.001
        msg.angular_velocity_covariance[8]     = 0.001

        self._pub_imu.publish(msg)

    def _publish_odom(self, data, stamp):
        x, y, theta, linear, angular, _ = data

        qz = math.sin(theta / 2.0)
        qw = math.cos(theta / 2.0)

        msg = Odometry()
        msg.header.stamp    = stamp
        msg.header.frame_id = self._odom_frame
        msg.child_frame_id  = self._base_frame

        msg.pose.pose.position.x    = x
        msg.pose.pose.position.y    = y
        msg.pose.pose.position.z    = 0.0
        msg.pose.pose.orientation.x = 0.0
        msg.pose.pose.orientation.y = 0.0
        msg.pose.pose.orientation.z = qz
        msg.pose.pose.orientation.w = qw

        msg.twist.twist.linear.x  = linear
        msg.twist.twist.angular.z = angular

        msg.pose.covariance[0]   = 0.01
        msg.pose.covariance[7]   = 0.01
        msg.pose.covariance[35]  = 0.05
        msg.twist.covariance[0]  = 0.01
        msg.twist.covariance[35] = 0.05

        self._pub_odom.publish(msg)

        # Broadcast odom→base_link TF
        if self._publish_tf:
            tf = TransformStamped()
            tf.header.stamp    = stamp
            tf.header.frame_id = self._odom_frame
            tf.child_frame_id  = self._base_frame
            tf.transform.translation.x = x
            tf.transform.translation.y = y
            tf.transform.translation.z = 0.0
            tf.transform.rotation.z    = qz
            tf.transform.rotation.w    = qw
            self._tf_broadcaster.sendTransform(tf)

        # ── Integrate wheel positions and publish /joint_states ──
        now_sec = stamp.sec + stamp.nanosec * 1e-9
        if self._last_odom_time is not None:
            dt = now_sec - self._last_odom_time
            if 0 < dt < 0.5:   # guard against stale timestamps
                v_left  = linear - (angular * self.WHEEL_BASE / 2.0)
                v_right = linear + (angular * self.WHEEL_BASE / 2.0)
                self._wheel_left_pos  += (v_left  / self.WHEEL_RADIUS) * dt
                self._wheel_right_pos += (v_right / self.WHEEL_RADIUS) * dt

        self._last_odom_time = now_sec

        js = JointState()
        js.header.stamp = stamp
        js.name         = ['Left_Wheel', 'Right_Wheel']
        js.position     = [self._wheel_left_pos, self._wheel_right_pos]
        js.velocity     = [0.0, 0.0]
        js.effort       = [0.0, 0.0]
        self._pub_joint_states.publish(js)

    def _publish_tof(self, data, stamp):
        left_mm, right_mm, back_mm = data

        def make_range(frame_id, range_mm):
            msg = Range()
            msg.header.stamp    = stamp
            msg.header.frame_id = frame_id
            msg.radiation_type  = Range.INFRARED
            msg.field_of_view   = 0.44
            msg.min_range       = 0.03
            msg.max_range       = 1.20
            msg.range           = float(range_mm) / 1000.0
            return msg

        self._pub_tof_l.publish(make_range('tof_left',  left_mm))
        self._pub_tof_b.publish(make_range('tof_back',  back_mm))
        self._pub_tof_r.publish(make_range('tof_right', right_mm))

    def _publish_battery(self, voltage: float, stamp):
        msg = BatteryState()
        msg.header.stamp = stamp
        msg.voltage      = voltage
        msg.present      = True

        pct = max(0.0, min(1.0, (voltage - 9.0) / (12.6 - 9.0)))
        msg.percentage   = pct

        msg.current             = float('nan')
        msg.charge              = float('nan')
        msg.capacity            = float('nan')
        msg.design_capacity     = float('nan')
        msg.power_supply_status = BatteryState.POWER_SUPPLY_STATUS_UNKNOWN
        msg.power_supply_health = BatteryState.POWER_SUPPLY_HEALTH_UNKNOWN
        msg.power_supply_technology = BatteryState.POWER_SUPPLY_TECHNOLOGY_LION

        self._pub_battery.publish(msg)

    # ── cmd_vel → TX ─────────────────────────────────────────────────────────

    def _cmd_vel_cb(self, msg: Twist):
        payload = struct.pack('<3f',
                              msg.linear.x,
                              msg.linear.y,
                              msg.angular.z)
        packet = build_packet(MSG_CMD_VELOCITY, payload)
        try:
            with self._serial_lock:
                self._serial.write(packet)
        except serial.SerialException as e:
            self.get_logger().error(f'Serial write error: {e}')

    # ── Diagnostics ──────────────────────────────────────────────────────────

    def _diag_cb(self):
        p = self._parser
        self.get_logger().info(
            f'[diag] bytes_rx={p.bytes_rx} '
            f'packets_ok={p.packets_ok} '
            f'crc_err={p.crc_errors} '
            f'frame_err={p.frame_errors}'
        )

    # ── Cleanup ──────────────────────────────────────────────────────────────

    def destroy_node(self):
        self._running = False
        self._rx_thread.join(timeout=1.0)
        if self._serial.is_open:
            self._serial.close()
        super().destroy_node()


def main(args=None):
    rclpy.init(args=args)
    node = SerialBridgeNode()
    try:
        rclpy.spin(node)
    except KeyboardInterrupt:
        pass
    finally:
        node.destroy_node()
        rclpy.shutdown()


if __name__ == '__main__':
    main()

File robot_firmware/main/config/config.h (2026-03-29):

#pragma once

// =============================================================
//  config.h — Single source of truth for all robot constants
//  Edit this file only. Never hardcode values elsewhere.
// =============================================================

// ── Firmware Version ─────────────────────────────────────────
#define FW_VERSION_MAJOR  0
#define FW_VERSION_MINOR  1
#define FW_VERSION_PATCH  0

// ── I2C Bus 0 — ToF Sensors (VL53L0X) ────────────────────────
#define TOF_I2C_PORT      I2C_NUM_0
#define TOF_SDA           14
#define TOF_SCL           13
#define TOF_I2C_FREQ_HZ   400000       // 400kHz fast mode

#define XSHUT_LEFT        12
#define XSHUT_BACK        11
#define XSHUT_RIGHT       10

#define ADDR_LEFT         0x30
#define ADDR_BACK         0x31
#define ADDR_RIGHT        0x32

// ── I2C Bus 1 — IMU (MPU6500) ────────────────────────────────
#define IMU_I2C_PORT      I2C_NUM_1
#define MPU_SDA           5
#define MPU_SCL           4
#define MPU_I2C_FREQ_HZ   400000
#define MPU_ADDR          0x68

// ── Battery ADC ───────────────────────────────────────────────
#define BATTERY_PIN       2            // GPIO2 = ADC1_CH1 on ESP32-S2
#define BATTERY_R1        10000.0f     // Top resistor (ohms)
#define BATTERY_R2        2550.0f      // Bottom resistor (ohms)
#define BATTERY_ADC_REF   3.3f         // ADC reference voltage
#define BATTERY_ADC_MAX   8191.0f      // 13-bit (ESP32-S2 default)
#define BATTERY_CAL       0.8047f      // Calibration factor (11.82/14.69)
#define BATTERY_SAMPLES   16           // Averaging samples

// ── Motors ────────────────────────────────────────────────────
#define RIGHT_PWM_PIN     21
#define RIGHT_DIR_PIN     33
#define RIGHT_FG_PIN      34

#define LEFT_PWM_PIN      15
#define LEFT_DIR_PIN      16
#define LEFT_FG_PIN       17

#define MOTOR_PWM_FREQ    25000        // 25kHz (above audible range)
#define MOTOR_PWM_RES     8            // 8-bit resolution (0-255)
#define MOTOR_PWM_STOP    255          // FIT0441 inverted: 255 = stop
#define MOTOR_PWM_FULL    0            // FIT0441 inverted: 0 = full speed

// ── UART to Raspberry Pi ──────────────────────────────────────
#define COMM_UART_PORT            UART_NUM_1
#define COMM_UART_RX_PIN          19
#define COMM_UART_TX_PIN          20
#define COMM_UART_BAUD            460800       // match RPi side
#define COMM_UART_BUF_SIZE        1024
#define COMM_TELEMETRY_PERIOD_MS  20           // 50 Hz

// ── Robot Geometry ────────────────────────────────────────────
#define WHEEL_DIAMETER_M      0.068f           // 68mm
#define WHEEL_CIRCUMFERENCE_M 0.21363f         // π × 0.068
#define WHEEL_SEPARATION_M    0.198f           // 198mm axle-to-axle

// ── FIT0441 Encoder ───────────────────────────────────────────
// Brushless motor, FG pin = frequency feedback
// 6 pulses per motor electrical cycle × 45:1 gearbox = 270 pulses/rev
#define MOTOR_GEAR_RATIO      45               // Pulses per motor rev
#define MOTOR_FG_PPR          6                // FG pulses per wheel rev
#define COUNTS_PER_REV        270              // = MOTOR_FG_PPR × MOTOR_GEAR_RATIO

// ── Motor direction inversion ─────────────────────────────────
// One motor is mounted mirrored — invert its direction here
// Set to 1 to invert, 0 for normal
// Test: if robot spins instead of going forward, flip one of these
#define MOTOR_LEFT_INVERT     1
#define MOTOR_RIGHT_INVERT    0
#define MAX_RPM               159.0f
#define MAX_VEL_MS            0.566f           // m/s at max RPM
#define MIN_VEL_MS            0.01f            // below this = treat as stop

// ── Cold-Start Recovery (feedback-driven) ───────────────────────
// FIT0441 ESC loses sync after idle. Detect via encoder feedback:
// if commanded but zero encoder delta for STALL_TICKS, reverse-prime.
// #define PRIME_STALL_TICKS     3               // consecutive zero-delta ticks before prime
// #define PRIME_REVERSE_OUTPUT  0.15f           // reverse prime intensity (0-1 normalized)
// #define PRIME_REVERSE_MS      10             // reverse prime duration (ms)
// #define PRIME_COOLDOWN_TICKS  2               // ticks to wait after prime before monitoring
// #define PRIME_MAX_RETRIES     2               // max consecutive primes per wake event

#define PRIME_REVERSE_OUTPUT  0.15f
#define PRIME_PULSE_MS        10

// ── PID Defaults (tune these) ─────────────────────────────────
#define PID_KP                0.3f
#define PID_KI                0.2f
#define PID_KD                0.0f
#define PID_INTEGRAL_MAX      0.5f             // Anti-windup clamp
#define PID_OUTPUT_MAX        1.0f             // Normalized -1.0 to 1.0

// ── Task Periods ─────────────────────────────────────────────
#define TASK_MOTOR_MS         50               // 20 Hz (Fix 1: longer window)
#define TASK_IMU_MS           10               // 100 Hz
#define TASK_TOF_MS           50               // 20 Hz
#define TASK_BATTERY_MS       500              // 2 Hz
#define TASK_COMMS_MS         20               // 50 Hz
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

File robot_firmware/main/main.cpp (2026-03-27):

#include <stdio.h>
#include "freertos/FreeRTOS.h"
#include "freertos/task.h"
#include "esp_log.h"
#include "config/config.h"
#include "common/robot_state.h"
#include "comms/comm_serial.h"
#include "tasks/task_motor.h"
#include "tasks/task_imu.h"
#include "tasks/task_tof.h"
#include "tasks/task_battery.h"
#include "tasks/task_comms.h"

static const char* TAG = "MAIN";

extern "C" void app_main(void) {
    ESP_LOGI(TAG, "==============================================");
    ESP_LOGI(TAG, "  Robot Firmware v%d.%d.%d",
             FW_VERSION_MAJOR, FW_VERSION_MINOR, FW_VERSION_PATCH);
    ESP_LOGI(TAG, "==============================================");

    robot_state_init();
    ESP_LOGI(TAG, "[OK] Shared state initialized");

    xTaskCreatePinnedToCore(task_motor,   "motor",   STACK_MOTOR,   NULL, PRIO_MOTOR,   NULL, CORE_MOTOR);
    ESP_LOGI(TAG, "[OK] Motor task started");

    xTaskCreatePinnedToCore(task_imu,     "imu",     STACK_IMU,     NULL, PRIO_IMU,     NULL, CORE_IMU);
    ESP_LOGI(TAG, "[OK] IMU task started");

    xTaskCreatePinnedToCore(task_tof,     "tof",     STACK_TOF,     NULL, PRIO_TOF,     NULL, CORE_TOF);
    ESP_LOGI(TAG, "[OK] ToF task started");

    xTaskCreatePinnedToCore(task_battery, "battery", STACK_BATTERY, NULL, PRIO_BATTERY, NULL, CORE_BATTERY);
    ESP_LOGI(TAG, "[OK] Battery task started");

    comm_serial_init();
    xTaskCreatePinnedToCore(task_comms,  "comms",   STACK_COMMS,   NULL, PRIO_COMMS,   NULL, CORE_COMMS);
    ESP_LOGI(TAG, "[OK] Comms task started");
}

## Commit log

2026-03-25 Add motor controller, odometry, and PID controller implementations
    - Implemented motor_controller.h and motor_controller.cpp for velocity PID control and odometry integration.
    - Created odometry.h and odometry.cpp for wheel odometry pose integration.
    - Added pid.h and pid.cpp for a generic PID controller implementation.
    - Developed task_motor and task_imu for motor control and IMU data handling.
    - Introduced task_tof for time-of-flight sensor data processing.
    - Added setup script and GUI launcher for ESP-IDF project management.
    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
2026-03-25 Update README.md to reflect current project structure, capabilities, and setup instructions
2026-03-25 Update README to reflect current project details
    Removed outdated project description and added a concise overview of the OPEN-01 robotics platform.
2026-03-25 Add battery monitoring functionality and related components
2026-03-25 Mark battery monitoring task as completed
2026-03-27 feat: Implement communication handling and telemetry
    - Added comms task to manage UART communication and telemetry data transmission.
    - Introduced comm_handler for processing incoming commands and building telemetry packets.
    - Enhanced robot_state to include command velocity and emergency stop functionalities.
    - Updated CMakeLists to include new comms and task_comms files.
    - Refactored motor task to respond to command velocities and emergency stop signals.
    - Created comm_serial for UART communication setup and data handling.
    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
2026-03-28 feat: Enhance motor control and communication logging
    - Added I2C bus recovery mechanism in drv_mpu6500.cpp
    - Improved motor initialization in hal_motor.cpp with ISR setup
    - Introduced hal_motor_debug_delta function for motor delta tracking
    - Updated command velocity logging in comm_handler.cpp and task_motor.cpp
    - Adjusted CMakeLists.txt to include necessary dependencies
    - Refactored config.h for better organization of motor constants
2026-03-28 feat: Add LDS-02 lidar node and unified bringup launch
2026-03-29 fix: use ttyS0 for ESP32 UART, ttyLIDAR udev rule for LDS-02
2026-03-29 fix: remove lidar from bringup, serial bridge only
2026-03-29 feat: implement cold-start recovery mechanism in motor task
2026-03-29 feat: Add URDF model and description package for OPEN-01
    - Added Robot_Assembly_1.urdf defining robot structure with base_link, wheels, IMU, and TOF sensor links.
    - Included STL mesh files for base_link, left/right wheels, IMU, and TOF sensors (left, right, back).
    - Created display.launch for visualizing the robot model in RViz.
    - Added gazebo.launch for simulating the robot in Gazebo.
    - Added package.xml with package metadata and dependencies for the description package.
    - Included Robot_Assembly_1.csv for additional robot configuration data.
    [Battery_12V.SLDPRT, DC_Motor_DF_Robot_FIT0441.SLDPRT, Display_Mount_OLED_1.3in.3MF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]
2026-03-29 feat: Add URDF and launch files for Robot Assembly 1
    - Created display.launch and gazebo.launch files to facilitate visualization and simulation of the Robot Assembly 1.
    - Added URDF model (Robot_Assembly_1.urdf) and associated meshes for the robot components including wheels, IMU, and TOF sensors.
    - Introduced a CSV file for the robot's link properties and a Python script for testing serial communication with the sensor.
    - Updated package.xml to include necessary dependencies for the new robot description package.
    [IMU.STL, Left_Wheel.STL, Right_Wheel.STL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]
2026-03-29 feat: Add open01_description ROS2 package with URDF model
    - Added open01.urdf defining robot structure with base_link, wheels, IMU, and TOF sensor links.
    - Migrated package from ROS1 catkin to ROS2 ament_cmake build system.
    - Updated CMakeLists.txt and package.xml for ROS2 compatibility.
    - Renamed all Robot_Assembly_1 references to open01_description.
    - Added joint_names_open01.yaml for joint configuration.
    - Updated .gitignore to exclude ROS2 build artifacts.
    [Robot_Assembly_1.csv, open01.csv, open01.urdf]
2026-03-29 feat: Publish /joint_states from wheel odometry in serial bridge
    - Added JointState publisher to serial_bridge_node for Left_Wheel and Right_Wheel.
    - Integrated wheel position from linear and angular velocity using wheel geometry.
    - Added WHEEL_BASE and WHEEL_RADIUS constants derived from URDF joint origins.
    - Updated bringup.launch.py to include robot_state_publisher with publish_frequency.
2026-03-30 fix: Remove empty IMU mesh, lowercase STL extensions in URDF
    [IMU.stl, Left_Wheel.stl, Right_Wheel.stl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]
2026-03-30 fix: Update URDF colors for OPEN-01
    [open01.urdf]
2026-03-30 feat: Add visualization launch package for OPEN-01 with URDF and RViz configuration
2026-04-05 feat(hardware): Add OPEN-01 PCB V1.0.0 initial design
    - ESP32-S2-SOLO-2 as main MCU with USB OTG programming interface
    - MP2393 buck converter (12V → 5V/3A) for Raspberry Pi power
    - AMS1117-3.3 LDO (5V → 3.3V) for MCU and sensor rail
    - SS34 Schottky diode for reverse polarity protection on VBAT
    - VL53L0X ToF sensors x3 (left, back, right) with XSHUT addressing
    - MPU6500 IMU on dedicated I2C bus 1
    - FIT0441 motor connectors with FG pull-ups on GPIO17 and GPIO34
    - Würth 2171830001 USB Type-C with CC1/CC2 5.1k pull-downs
    - WL-ICLED RGB LED (GPIO6/7) with 330Ω series resistors
    - Dialight 598-8020-107F power indicator LED with 1kΩ series resistor
    - BOOT/RST buttons with debounce caps and I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
    [open-01-pcb.kicad_pcb, open-01-pcb.kicad_sch, open-01-pcb_v1.0.0_step_file.step]
2026-04-05 chore: Remove history submodule for open-01 PCB
2026-04-05 chore: Add initial STEP file for PCB design version 1.0.0
    [open-01-pcb_v1.0.0_step_file.step]
